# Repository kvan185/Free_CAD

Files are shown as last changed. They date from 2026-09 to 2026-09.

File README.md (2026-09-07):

# HỆ THỐNG TRỐNG RANG: CÁNH ĐẢO LA SẮT CHẠM CÂY TRỤ ĐỂ HÀN VÀO & 10 CÂY CHỐNG XEN KẼ (FREECAD 3D)

---

## 1. Thông Số Kỹ Thuật: Cánh Đảo Trong Chạm Trực Tiếp Cây Trụ Để Hàn Vào

### A. 5 CÁNH ĐẢO TRONG (BẢN RỘNG 10CM, DÀY 0.8CM, DÀI 65CM, KÉO DÀI RA PHÍA SAU)
- **Vật liệu**: Thanh la sắt bản rộng **$10\text{ cm}$ ($100\text{ mm}$)**, dày **$0.8\text{ cm}$ ($8\text{ mm}$)**.
- **Vị trí theo bán kính (Nằm ngay giữa thân 5 cây chống)**:
  - Cây chống dài từ cây láp ($R = 32.5\text{ mm}$) đến thành trống ($R = 392\text{ mm}$), có điểm chính giữa ở $R = 212.25\text{ mm}$.
  - Cánh đảo trong bản $10\text{ cm}$ được đặt đối xứng ngay điểm giữa: **$R_{\text{in}} = 162\text{ mm} \rightarrow R_{\text{out}} = 262\text{ mm}$** (tâm cánh $R = 212\text{ mm}$).
  - **Khoảng cách đến cây láp**: Cách mặt cây láp **$129.5\text{ mm}$ ($\approx 13\text{ cm}$)** $\rightarrow$ **Tuyệt đối KHÔNG áp sát vào cây láp, tạo khoảng trống thông thoáng cực lớn quanh trục.**
  - **Khoảng cách đến vỏ trống**: $130\text{ mm}$ ($13\text{ cm}$) đối xứng hoàn hảo.
  - **Khoảng cách đến cánh ngoài**: Cách mép trong cánh ngoài $60\text{ mm}$ ($6\text{ cm}$).
- **Vị trí dọc trục & Chiều dài (Kéo dài ra phía sau)**:
  - Chiều dài: **$65\text{ cm}$ ($650\text{ mm}$)**.
  - Trải từ tầng 5 cây chống gần đầu ($Y = -400\text{ mm}$), đi xuyên qua và gối hàn lên tầng 5 cây chống giữa ($Y = +100\text{ mm}$), rồi **kéo dài tiếp thêm $15\text{ cm}$ về phía sau** đến $Y = +250\text{ mm}$.
  - Cách miệng sau của trống $25\text{ cm}$ để luồng gió hút khói và cửa cấp hạt thông thoáng hoàn hảo.
- **Bước xoắn & Góc xoắn**: Bước xoắn $P = 1083.3\text{ mm}$, `lefthand = True` $\rightarrow$ Xoắn ngược đúng **$6/10$ vòng ($216^\circ$)**.
- **Tác dụng**: Đón dòng hạt rơi từ đỉnh xuống vùng giữa và hắt ngược lại theo chiều $Y-$, tạo luồng đối lưu tuần hoàn liên tục.
- **Phân bố**: 5 cánh ở các góc **$36^\circ, 108^\circ, 180^\circ, 252^\circ, 324^\circ$**.
- **Màu hiển thị 3D**: Xanh ngọc lục bảo tươi sáng.

---

### B. 5 CÁNH ĐẢO NGOÀI (CHẠM 5 CÂY CHỐNG ĐỂ HÀN & BÁM THÀNH TRỐNG)
- **Vật liệu**: Thanh la sắt bản rộng **$7\text{ cm}$ ($70\text{ mm}$)**, dày **$0.5\text{ cm}$ ($5\text{ mm}$)**.
- **Bán kính làm việc**: Cạnh ngoài bám sát thành trong trống $R = 392\text{ mm}$, cạnh trong $R = 322\text{ mm}$ (cao đứng đúng $7\text{ cm}$).
- **Chiều dài trục**: $H = 960\text{ mm}$ (từ $Y = -480\text{ mm}$ đến $+480\text{ mm}$).
- **Bước xoắn & Độ xoắn**: $P = 1600.0\text{ mm}$ $\rightarrow$ **Giữ nguyên chuẩn xác độ xoắn $6/10$ vòng ($216.0^\circ$)**.
- **Căn chỉnh pha tiếp xúc hàn**:
  - Tại vị trí tầng 5 cây chống bên 1 ($Y = -400\text{ mm}$), quãng đường xoắn từ gốc $Y = -480\text{ mm}$ là $\Delta Y = 80\text{ mm}$.
  - Góc xoắn tích lũy tại $Y = -400\text{ mm}$ là: $\frac{80}{1600} \times 360^\circ = +18.0^\circ$.
  - Bù góc lệch pha ban đầu: **`offset_goc = -18.0°`**.
  - **Kết quả**: Tại $Y = -400\text{ mm}$, cả 5 cánh đảo ngoài đi qua chính xác các góc $0^\circ, 72^\circ, 144^\circ, 216^\circ, 288^\circ$, **chạm khít 100% không còn khe hở vào 5 cây chống để thợ hàn đính/hàn ngấu liên kết chắc chắn!**
- **Tác dụng**: Cào sát thành trống, cuốn và xúc hạt cuộn tịnh tiến xuôi liên tục theo chiều $Y+$.
- **Màu hiển thị 3D**: Đỏ cam nổi bật.

---

### C. HỆ THỐNG 10 CÂY CHỐNG BỐ TRÍ XEN KẼ NHAU (VỪA CHẠM CẢ 2 TẦNG ĐỂ HÀN)
- **Vật liệu**: **Ống sắt tròn $\varnothing 20\text{ mm}$, rỗng ruột, dày $2\text{ mm}$** (ĐK trong $\varnothing 16\text{ mm}$).
- **Bên 1 - 5 cây gần đầu** (Cách miệng trống $10\text{ cm}$ $\rightarrow$ $Y = -400\text{ mm}$):
  - Góc ban đầu: Bù góc pha **$-4.5^\circ$** $\rightarrow$ Các góc: **$-4.5^\circ, 67.5^\circ, 139.5^\circ, 211.5^\circ, 283.5^\circ$**.
  - **Tiếp xúc**: Vừa chạm sát sườn mặt bên của 5 cánh ngoài la sắt (khoảng cách $0.687\text{ mm}$), **hoàn toàn giống như 5 cây ở giữa**, không bị cắt xẻ vào lòng ống, tạo góc tiếp xúc lý tưởng để thợ hàn đường hàn ngấu.
- **Bên 2 - 5 cây ở giữa** (Cách miệng lỗ đầu kia $40\text{ cm}$ $\rightarrow$ $Y = +100\text{ mm}$):
  - Góc ban đầu: **$+36.0^\circ$** $\rightarrow$ Các góc: **$36^\circ, 108^\circ, 180^\circ, 252^\circ, 324^\circ$**.
  - **Tiếp xúc**: Vừa chạm sát sườn mặt bên của 5 cánh ngoài (khoảng cách $0.687\text{ mm}$).
- **Tổng kết**: Cả 10 cây chống đều tiếp xúc tiếp tuyến êm ái ("vừa chạm") với 5 cánh ngoài để hàn.

---

### D. HỆ THỐNG TRỐNG RANG 2 LỚP CÁCH KHÍ & CÂY LÁP
- **Vỏ trống trong**: Dài $1\text{ m}$ ($1000\text{ mm}$), đường kính ngoài $80\text{ cm}$ ($800\text{ mm}$), thành dày $0.8\text{ cm}$ ($8\text{ mm}$, $R_{\text{in}} = 392\text{ mm} \rightarrow R_{\text{out}} = 400\text{ mm}$).
- **Lớp áo ngoài cách khí**:
  - Hở **$1\text{ cm}$ ($10\text{ mm}$)** đệm không khí so với vỏ trong ($R_{\text{ao\_in}} = 410\text{ mm}$).
  - Độ dày vỏ ngoài: **$0.5\text{ cm}$ ($5\text{ mm}$)** ($R_{\text{ao\_out}} = 415\text{ mm} \rightarrow \varnothing 830\text{ mm} = 83\text{ cm}$).
  - Chiều dài: $1\text{ m}$ ($1000\text{ mm}$).
  - **Tác dụng**: Tạo lớp đệm khí cách nhiệt chống táp lửa trực tiếp, tránh cháy xém hạt và giữ nhiệt đối lưu hoàn hảo.
- **Cây láp (cây trụ chính)**: Dài tổng $1\text{ m}2$ ($1200\text{ mm}$), thân giữa $\varnothing 65\text{ mm} \times 1000\text{ mm}$ ($R = 32.5\text{ mm}$), 2 đầu tiện bậc $\varnothing 60\text{ mm} \times 10\text{ cm}$ ($100\text{ mm}$).

### E. HỆ THỐNG 2 MẶT MÁY GÁ TRỐNG (TRƯỚC & SAU): SẮT TẤM DÀY 1.8CM, VÒNG TRÒN PHI 96CM, HÌNH THANG CHÂN 1.1M
- **Vật liệu & Độ dày**: Sắt tấm kết cấu chịu lực dày **$1.8\text{ cm}$ ($18\text{ mm}$ / 18 ly)** nguyên khối.
- **Bố trí 2 đầu máy đối xứng gá trống**:
  - **Mặt máy trước**: Tọa độ $Y = -518.0\text{ mm} \rightarrow -500.0\text{ mm}$ (ngay miệng trước của trống).
  - **Mặt máy sau**: Tọa độ $Y = +500.0\text{ mm} \rightarrow +518.0\text{ mm}$ (ngay miệng sau của trống).
  - Khoảng cách lọt lòng giữa 2 mặt máy: Đúng **$1000\text{ mm} = 1.0\text{ m}$**, ôm trọn chiều dài thân trống rang.
- **Phía trên hình tròn lớn hơn 10cm cong thắt eo vào 1 tí**:
  - Cung tròn bán kính $R = 480\text{ mm}$ (**$\varnothing 960\text{ mm} = 96\text{ cm}$**, lớn hơn $10\text{ cm}$ so với $\varnothing 86\text{ cm}$ trước đó), bao phủ rộng rãi lớp vỏ áo ngoài ($R_{\text{ao}} = 415\text{ mm}$) với vành gờ che bảo vệ an toàn $65\text{ mm}$ ($6.5\text{ cm}$) mỗi bên.
  - Cung tròn uốn cong qua đường xích đạo ($Z = 0$), tiếp tục thắt cong vào trong 1 tí đến góc $-40^\circ$ ($X = \pm 367.7\text{ mm}, Z = -308.5\text{ mm}$) ôm sát theo sườn dưới của trống.
- **Phía dưới kết hợp liền khối thành hình thang cân (bên dưới dài hơn bên trên)**:
  - **Đáy trên của hình thang**: Chính là eo thắt cong vào của cung tròn, bề rộng $W_{\text{top}} = 735.4\text{ mm} \approx 735\text{ mm}$ tại $Z = -308.5\text{ mm}$.
  - **Đáy dưới của hình thang**: Nằm phẳng trên sàn xưởng tại $Z = -850.0\text{ mm}$, bề rộng **$W_{\text{bottom}} = 1100\text{ mm} = 1.1\text{ m}$** ($X = -550\text{ mm} \rightarrow +550\text{ mm}$).
  - Đúng chuẩn hình thang cân với **đáy dưới ($1100\text{ mm}$) dài hơn đáy trên ($735\text{ mm}$)**.
  - Hai cạnh sườn xiên choãi xuống mặt đất với góc nghiêng $\approx 71.4^\circ$.
  - Tổng chiều cao mặt máy từ đỉnh vòng tròn đến đáy phẳng là **$1330\text{ mm}$ ($1.33\text{ m}$)** (từ $Z = -850\text{ mm}$ đến $Z = +480\text{ mm}$).
  - **Tác dụng**: Cặp chân đế phẳng siêu rộng $1.1\text{ m}$ ở hai đầu tiếp xúc vững chắc trên mặt sàn hoặc dễ dàng bắt bu-lông vào dầm thép bệ máy, chống rung lắc, chống lật tuyệt đối khi trống quay đảo hàng tạ nông sản.
- **Lỗ lọt đầu cốt ở cả 2 mặt máy**: Mỗi mặt có 1 lỗ tròn đường kính **$\varnothing 65\text{ mm}$** ($R = 32.5\text{ mm}$) tại tâm $(0, 0)$, lọt đầu cốt láp $\varnothing 60\text{ mm}$ với khe hở an toàn $2.5\text{ mm}$ đều quanh cốt. Mỗi đầu cốt láp nhô ra ngoài mặt bích đúng **$82\text{ mm}$** để gá lắp gối bi đỡ trục (UCP/UCFL) và puly/nhông xích truyền động.
- **Tính năng cơ học**: Cả 2 mặt máy là chi tiết **tĩnh (cố định vào khung bệ máy)**, đứng yên làm bệ đỡ vững chắc cho toàn bộ trống quay.

---

### G. MIỆNG RA HÀNG TẠI MẶT TRƯỚC: DÀI 50CM, 2 BÊN THÀNH CAO ĐÚNG 10CM (TỪ MÉP DƯỚI LÊN), ĐÁY CONG THEO TRỐNG R392MM
- **Vị trí gia công**: Cắt xuyên thủng qua tấm thép dày **$1.8\text{ cm}$ ($18\text{ mm}$)** của Mặt máy trước (`obj_mat_truoc`, $Y = -518\text{ mm} \rightarrow -500\text{ mm}$). Mặt máy sau giữ liền khối kín 100% để chống lọt khí.
- **Biên dạng hình học chuẩn xác**:
  - **2 bên thành đứng**: Cao đúng **$10\text{ cm} = 100\text{ mm}$** tính từ mép dưới của cung tròn lòng trống ($Z = -301.9\text{ mm}$) thẳng đứng lên ($Z = -201.9\text{ mm}$) tại hai bên biên $X = -250.0\text{ mm}$ và $X = +250.0\text{ mm}$.
  - **Cạnh trên (Đường thẳng)**: Đường thẳng nằm ngang dài đúng **$50\text{ cm} = 500\text{ mm}$** (từ $X = -250\text{ mm}$ đến $X = +250\text{ mm}$) tại cao độ $Z = -201.9\text{ mm}$.
  - **Cạnh dưới (Đường cong theo trống)**: Cung tròn uốn cong ôm sát thành trong của trống rang với bán kính **$R = 392\text{ mm}$** (từ $X = -250\text{ mm}, Z = -301.9\text{ mm}$ qua đáy thấp nhất $X = 0, Z = -392.0\text{ mm}$ đến $X = +250\text{ mm}, Z = -301.9\text{ mm}$).
  - **Chiều cao lớn nhất tại tâm (từ đáy lên đỉnh)**: Đạt **$190\text{ mm} = 19.0\text{ cm}$** (từ $Z = -392.0\text{ mm}$ lên $Z = -201.9\text{ mm}$), mở rộng khẩu độ đón luồng hạt trút ra cực kỳ thông thoáng.
- **Ưu điểm cơ khí & Công năng vận hành**:
  - **Xả sạch 100% không đọng hạt**: Đáy miệng xả trùng khớp hoàn hảo với thành trong lòng trống ($R = 392\text{ mm}$), không có bất kỳ gờ hay bậc cản nào $\rightarrow$ Nông sản/cà phê sau khi rang chín được các cánh đảo ngoài xúc trút trơn tru ra ngoài không hề bị sót hay vướng cháy khét.
  - **Đảm bảo độ cứng vững kết cấu**: Khoảng "thịt" thép nguyên khối chịu lực giữa cạnh trên miệng xả ($Z = -201.9\text{ mm}$) và mép dưới lỗ cốt trục $\varnothing 65\text{ mm}$ ($Z = -32.5\text{ mm}$) còn tới **$169.4\text{ mm} \approx 17\text{ cm}$**. Tấm thép 18 ly siêu dày giữ vững độ cứng chịu tải rung động mà không hề bị võng hay biến dạng.
  - **Khoảng sáng xả liệu thoáng rộng**: Từ đáy miệng xả ($Z = -392\text{ mm}$) xuống mặt tấm chân đế ($Z = -850\text{ mm}$) có khoảng cách tĩnh lên đến **$458\text{ mm} \approx 46\text{ cm}$**, cực kỳ thuận tiện để bố trí máng hứng, phễu rót và đưa bàn làm nguội/thau hứng cà phê vào bên dưới.

---

### H. LỖ THĂM HÀNG PHI 30MM & CÂY THĂM HÀNG NẰM NGANG CÂY LÁP (KHÔNG CẤN CÁNH ĐẢO)
- **Vị trí gia công trên Mặt máy trước**:
  - Tọa độ tâm lỗ: **Nằm ngang cây láp ($Z = 0.0\text{ mm}$)**, bố trí phía bên trái tại **$X = -200.0\text{ mm}, Z = 0.0\text{ mm}$** (vị trí góc 9 giờ đón trọn dòng hạt cuộn trút xuống).
  - Đường kính lỗ: **$\varnothing 30\text{ mm}$ ($R = 15\text{ mm}$)**, khoan xát xiên qua tấm sắt dày $1.8\text{ cm}$ ($18\text{ mm}$) của mặt máy trước.
- **Cấu tạo Cây thăm hàng (Trier / Sampler spoon)**:
  - **Thân ống & Máng xúc mẫu (Inox)**: Ống inox $\varnothing 24\text{ mm}$, có bích chặn $\varnothing 38\text{ mm}$ tì lên mặt ngoài. Chiều sâu đút vào trống $7.2\text{ cm}$ (đầu tip tại $Y = -427.6\text{ mm}$), phay rãnh lòng máng ngửa lên trên ($+Z$) hứng trọn hạt rơi.
  - **Tay cầm cách nhiệt**: Gỗ tiện công thái học $\varnothing 32\text{ mm}$, dài $11\text{ cm}$, nhô ngang sang bên trái phía trước mặt máy tại cao độ $Z = 0$, chống nóng an toàn tuyệt đối khi rút/xoay lấy mẫu thử.
- **Tư thế lắp đặt: ĐỂ XÉO TRONG MẶT PHẲNG NẰM NGANG ($Z = 0$)**:
  - Góc xiên vào tâm: $\approx 16.7^\circ$ trong mặt phẳng nằm ngang ($Z = 0.0\text{ mm}$, vector $\vec{V} = (30, 100, 0)$) hướng chếch vào lòng trống.
  - Hướng miệng xúc mẫu: Ngửa thẳng lên trên ($+Z$) để dòng nông sản/hạt cà phê đảo cuộn từ đỉnh trống rơi tự nhiên lọt đầy máng.
- **Tính toán cơ khí: TUYỆT ĐỐI KHÔNG CẤN CÁNH ĐẢO**:
  - **Với 5 Cánh đảo ngoài ($R = 322 - 392\text{ mm}$)**: Cây thăm nằm ở bán kính $R = 175.6\text{ mm}$, cách xa mép trong cánh ngoài tới **$146.4\text{ mm} \approx 14.6\text{ cm}$** $\rightarrow$ Tuyệt đối an toàn.
  - **Với 10 Cây chống tròn ($\varnothing 20\text{ mm}$ tại $Y = -400\text{ mm}$)**: Đầu tip cây thăm dừng tại $Y = -427.6\text{ mm}$, cách mép cây chống tới **$17.6\text{ mm}$** khoảng hở an toàn.
  - **Với 5 Cánh đảo trong (bắt đầu tại $Y = -400\text{ mm}$)**: Cây thăm cách đầu cánh trong tới **$27.6\text{ mm}$**.
  - **Với Cốt trục chính / Cây láp ($\varnothing 65\text{ mm}$, $R = 32.5\text{ mm}$)**: Cách mặt trục láp tới **$143.1\text{ mm} \approx 14.3\text{ cm}$**.
  - **Kết luận**: Cây thăm hàng nằm ngang trục láp đạt độ tiện dụng tối ưu, đứng yên hoặc xoay rút lấy mẫu trơn tru khi máy đang vận hành mà không hề va quẹt vào bất kỳ chi tiết quay nào!

---

### I. CỬA BUỒNG ĐỐT MẶT SAU: LỖ 50x30CM, TẬN DỤNG TẤM SẮT ĐÃ CẮT LÀM CỬA, KHE CẮT 1MM, 2 BẢN LỀ MỞ VỀ BÊN TRÁI
- **Vị trí gia công**: Cắt bằng máy CNC xuyên thủng qua tấm thép dày **$1.8\text{ cm}$ ($18\text{ mm}$)** của Mặt máy sau (`obj_mat_sau`, $Y = +500.0\text{ mm} \rightarrow +518.0\text{ mm}$).
- **Kích thước lỗ khoét khung**:
  - **Chiều dài (bề rộng theo phương ngang)**: **$50\text{ cm} = 500\text{ mm}$**, cân đối chính giữa từ $X = -250.0\text{ mm}$ đến $X = +250.0\text{ mm}$.
  - **Chiều cao (theo phương đứng)**: Giảm còn đúng **$30\text{ cm} = 300\text{ mm}$** (từ $Z = -800.0\text{ mm}$ lên $Z = -500.0\text{ mm}$).
  - **Khoảng cách tới chân máy**: Đáy mép dưới đặt tại **$Z = -800.0\text{ mm}$**, cách chân đế máy ($Z = -850.0\text{ mm}$) đúng **$5\text{ cm} = 50\text{ mm}$**.
- **Cấu tạo cánh cửa tận dụng phôi sắt đã cắt (Kerf cắt 1mm)**:
  - **Dùng lại tấm sắt 18mm đã cắt**: Tiết kiệm vật tư tối đa, vừa khít hoàn hảo vào khung cửa.
  - **Đường cắt (kerf) chuẩn CNC**: Chừa khe hở đều **$1.0\text{ mm}$** cả 4 cạnh xung quanh:
    - Kích thước cánh cửa: Rộng **$49.8\text{ cm} = 498\text{ mm}$** x Cao **$29.8\text{ cm} = 298\text{ mm}$** x Dày **$1.8\text{ cm} = 18\text{ mm}$**.
- **Hệ thống 2 bản lề cối & Khóa cửa (Mở về bên trái)**:
  - **2 Bản lề cối hàn bên trái**: Hàn dọc mép bên trái ($X = +249.5\text{ mm}$, $Y = 518\text{ mm}$ khi đứng nhìn từ phía sau), bố trí tại cao độ $Z = -560\text{ mm}$ và $Z = -740\text{ mm}$. Cối đường kính $\varnothing 20\text{ mm}$ chịu lực siêu bền, cho phép **cánh cửa mở xoay mượt mà về bên trái** góc từ $0^\circ$ đến $120^\circ$.
  - **Tay khóa then gài L-handle bên phải**: Bố trí tại $X = -210\text{ mm}, Z = -650\text{ mm}$, có lưỡi gài giữ chặt cánh cửa khi đóng kín buồng đốt.
- **Tính toán cơ khí & Khoảng cách an toàn**:
  - **Khoảng thịt thép lên cốt trục láp**: Từ đỉnh lỗ ($Z = -500.0\text{ mm}$) lên tới lỗ cốt láp $\varnothing 65\text{ mm}$ ($Z = -32.5\text{ mm}$) tăng lên tới **$467.5\text{ mm} \approx 47\text{ cm}$** thép tấm 18 ly nguyên khối $\rightarrow$ Cực kỳ cứng vững, chống rung lắc hoàn toàn.
  - **Khoảng cách tới gầm trống rang**: Cách đáy vỏ ngoài trống ($Z = -415\text{ mm}$) tới **$85\text{ mm} = 8.5\text{ cm}$** dải thép liền khối bảo vệ.
- **Công năng vận hành thực tế**:
  - Đóng vai trò là **Cửa buồng đốt củi / nạp nhiệt / thông gió**: Dễ dàng mở cửa về bên trái để đưa củi lửa hoặc đầu đốt gas vào, đóng kín cửa khi rang để giữ nhiệt, và mở ra vệ sinh cào tro xỉ định kỳ cực kỳ tiện lợi.

---

### J. BUỒNG ĐỐT CỦI & LÒNG MÁNG GẠCH SA MỐT CAO 50CM ÔM TRỐNG CÁCH 1CM GIỮ NHIỆT TUYỆT ĐỐI (KT 30x5x10CM)
- **Yêu cầu thiết kế**: "tôi chỉ cần gạch cao lên 50cm thôi".
- **Kích thước từng viên gạch sa mốt tiêu chuẩn**:
  - Chiều dài: **$30\text{ cm} = 300.0\text{ mm}$**
  - Chiều rộng: **$10\text{ cm} = 100.0\text{ mm}$**
  - Chiều dày: **$5\text{ cm} = 50.0\text{ mm}$**
  - Mạch vữa xây chịu nhiệt: $1.5\text{ mm}$ sắc nét mô phỏng chân thực kết cấu xây lò.
- **Cấu tạo không gian 3 thành phần & Kỹ thuật cưa gọt gạch ôm sát trống (Nằm gọn dưới trống)**:
  1. **Sàn đáy buồng đốt (Hearth Floor)**:
     - Lát kín trực tiếp trên mặt tấm sắt chân máy từ $Z = -850.0\text{ mm}$ đến $Z = -800.0\text{ mm}$ (dày đúng $5\text{ cm} = 50\text{ mm}$, 1 viên gạch nằm).
     - **Bảo vệ cách nhiệt $100\%$**: Ngăn chặn hoàn toàn nhiệt độ cực cao của than hồng ($800 - 1000^\circ\text{C}$) truyền xuống tấm sắt chân máy $5\text{ mm}$ và sàn xưởng, chống cong vênh bệ máy.
     - **Bằng phẳng khít mép dưới cửa sau**: Mặt sàn gạch ở cao độ $Z = -800.0\text{ mm}$, trùng khớp $100\%$ với ngưỡng dưới của cửa sau ($Z = -800.0\text{ mm}$), giúp thao tác đưa củi vào và cào tro xỉ ra trơn tru tuyệt đối, không có gờ cản trở.
     - Kích thước sàn: Rộng **$700\text{ mm} = 70\text{ cm}$** ($7$ hàng gạch $\times 100\text{ mm}$, $X \in [-350, +350\text{ mm}]$), Dài **$1000\text{ mm} = 1\text{ m}$** ($Y \in [-500, +500\text{ mm}]$) xây so le các hàng.
  2. **Hai vách hông bao đúng 1 lớp gạch dày $10\text{ cm}$, chừa lòng ngang $50\text{ cm}$, cao 9 hàng đến đáy trống**:
     - **Lòng trong chừa đúng ngang $50\text{ cm} = 500\text{ mm}$**: $X \in [-250, +250\text{ mm}]$, khớp hoàn hảo $100\%$ với chiều rộng cửa sau $50\text{ cm}$.
     - **Bao quanh đúng 1 lớp gạch (dày $10\text{ cm} = 100\text{ mm}$)**: Vách trái từ $X \in [-350, -250\text{ mm}]$, vách phải từ $X \in [+250, +350\text{ mm}]$.
     - **Tổng bề rộng phủ bì chỉ $70\text{ cm} = 700\text{ mm}$**: Nhỏ hơn bề rộng eo thắt hẹp nhất của mặt máy ($73.5\text{ cm}$, $X = \pm 367.7\text{ mm}$) $\rightarrow$ Dư an toàn ít nhất $1.8\text{ cm}$ mỗi bên, **lọt thỏm hoàn toàn dưới gầm trống và bên trong mặt máy, tuyệt đối không bị lòi ra ngoài!**
     - **Chiều cao xây đến đáy trống**: Xây **9 hàng gạch** ($45\text{ cm}$ từ sàn gạch, $50\text{ cm}$ từ chân máy) lên tới $Z = -350.0\text{ mm}$.
     - **Kỹ thuật cưa gọt gạch tạo hình ($R_{\text{cắt}} = 425.0\text{ mm}$)**: Cắt vát vòm cong trụ tròn bán kính **$R_{\text{cut}} = 425.0\text{ mm}$** dọc theo trục $Y$.
     - **Khe hở giữ nhiệt tuyệt đối $1\text{ cm} = 10\text{ mm}$**: So với bán kính vỏ áo ngoài $R_{\text{ao}} = 415.0\text{ mm}$, khoảng hở tròn đều là **$425 - 415 = 10.0\text{ mm} = 1\text{ cm}$** ôm sát quanh đáy trống.
     - **Hiệu quả nhiệt động học**: Khí nóng và bức xạ từ than củi bị bẫy kín trong khe hở $1\text{ cm}$ ôm quanh thân trống, không cho nhiệt lượng thoát sang hai bên hông máy, giúp tiết kiệm củi tối đa và tăng tốc độ gia nhiệt trống rang.
  3. **Vách chắn nhiệt phía trước (Front Wall)**:
     - Xây chắn ở đầu trước: $Y \in [-500, -400\text{ mm}]$ (dày $10\text{ cm}$), $X \in [-250, +250\text{ mm}]$ (rộng $50\text{ cm}$).
     - Đỉnh vách được gọt vòm cong $R_{\text{cut}} = 425\text{ mm}$ ôm cách đáy trống ngoài $1\text{ cm}$ (đỉnh tại $X=0$ đạt $Z = -425\text{ mm}$).
     - **Hoàn toàn không cấn miệng ra hàng**: Miệng ra hàng mặt trước nằm từ $Z = -302\text{ mm}$ lên $Z = -202\text{ mm}$, cao hơn đỉnh vách trước tới $123\text{ mm} \approx 12.3\text{ cm}$ $\rightarrow$ Hạt xả trút $100\%$ không bị vướng.
- **Kích thước lòng buồng đốt**: Rộng **$50\text{ cm}$** $\times$ Chiều dài buồng đốt **$90\text{ cm}$** ($Y \in [-400, +500\text{ mm}]$), chứa thoải mái củi dài $60 - 80\text{ cm}$.
- **Cào tro và nạp củi thuận tiện qua cửa sau 50x30cm**: Đáy cửa sau phẳng lì tiếp nối mặt sàn gạch sa mốt, cào tro xỉ ra ngoài dễ dàng trong 1 nốt nhạc.

---

### F. HỆ THỐNG CHÂN ĐẾ MÁY HÌNH CHỮ NHẬT: SẮT TẤM DÀY 0.5CM (5MM), DƯ MỖI BÊN 0.5CM (5MM)
- **Vật liệu & Độ dày**: Thép tấm kết cấu dày chuẩn **$0.5\text{ cm} = 5.0\text{ mm}$ (5 ly)** nguyên tấm.
- **Kích thước bao chuẩn xác tuyệt đối**:
  - **Bề ngang máy (Trục $X$ - Trái & Phải)**:
    - Đáy chân 2 mặt máy có bề rộng $1100.0\text{ mm} = 1.1\text{ m}$ ($X = -550.0\text{ mm} \rightarrow +550.0\text{ mm}$).
    - Dư ra mỗi bên trái và phải đúng **$0.5\text{ cm} = 5.0\text{ mm}$** $\rightarrow$ Biên $X = -555.0\text{ mm} \rightarrow +555.0\text{ mm}$.
    - **Tổng chiều rộng chân đế**: **$W = 1110.0\text{ mm} = 111.0\text{ cm} = 1.11\text{ m}$**.
  - **Chiều dọc máy (Trục $Y$ - Trước & Sau)**:
    - Mặt ngoài mặt máy trước tại $Y = -518.0\text{ mm}$, mặt ngoài mặt máy sau tại $Y = +518.0\text{ mm}$ (khoảng bao phủ $1036.0\text{ mm}$).
    - Dư ra mỗi bên trước và sau đúng **$0.5\text{ cm} = 5.0\text{ mm}$** $\rightarrow$ Biên $Y = -523.0\text{ mm} \rightarrow +523.0\text{ mm}$.
    - **Tổng chiều dài chân đế**: **$L = 1046.0\text{ mm} = 104.6\text{ cm} = 1.046\text{ m}$**.
  - **Chiều cao & Cao độ lắp đặt (Trục $Z$)**:
    - Độ dày tấm: $H = 5.0\text{ mm}$.
    - Đáy 2 mặt máy tựa khít lên mặt trên của chân đế tại $Z = -850.0\text{ mm}$.
    - Mặt dưới chân đế tiếp xúc mặt sàn tại $Z = -855.0\text{ mm}$ (Điểm gốc: $X = -555.0, Y = -523.0, Z = -855.0\text{ mm}$).
- **Tác dụng cơ khí**:
  - Khóa cứng và liên kết 2 mặt máy trước - sau thành một khối khung giằng chassi hoàn chỉnh.
  - Phân bổ đều trọng lượng máy (hàng trăm kg) xuống mặt nền xưởng, triệt tiêu hoàn toàn ứng suất rung lắc khi trống quay đảo nông sản tải nặng.
  - Vành gờ dư $5\text{ mm}$ đều 4 phía tạo đường rãnh chuẩn cho thợ cơ khí chạy đường hàn góc liên kết bệ máy hoặc khoan lỗ bắt bu-lông neo chân đế (anchor bolts).

---

## 2. Bảng Điều Khiển Thông Minh (Smart Control Dashboard)
- **Auto-Clean**: Tự động đóng tất cả tab cũ trong FreeCAD trước khi mở mới.
- **Giao diện tinh gọn, thông minh**: Xóa bỏ toàn bộ khối văn bản thừa rườm rà trên hộp thoại, chuyển toàn bộ thông số kỹ thuật chi tiết vào tài liệu markdown [`THONG_SO_KY_THUAT.md`](file:///c:/VAN/CAD/THONG_SO_KY_THUAT.md).
- **Nút "📖 Thông Số (MD)"**: Đặt ngay thanh tiêu đề, 1-click mở ngay tài liệu kỹ thuật đầy đủ.
- **Thanh trạng thái sống (Live Status)**: Hiển thị thời gian thực trạng thái quay động cơ (`🟢 Đang quay` / `🔴 Đã tạm dừng`), góc xoay độ, chiều quay (Thuận / Nghịch) và trạng thái cửa sau (Đóng / Mở 120°).
- **Preset tốc độ thông minh (1-Click Speed)**: Thanh trượt 5 - 120 RPM kèm các nút chọn nhanh `20 RPM (Chậm)`, `40 RPM (Chuẩn)`, `60 RPM (Nhanh)`.
- **Nút "🚪 Mở Cửa Sau (120°)"**: Cơ cấu cửa xoay mở rộng **$120^\circ$** về bên trái, áp sát sườn máy, giải phóng $100\%$ miệng cửa để nạp củi và cào tro phẳng đáy sàn gạch.
- **Nhóm Quan sát**: `👁 Xuyên Thấu Vỏ Trống` (transparency 50%), `📦 Ẩn/Hiện Vỏ Trống`, `🛡 Ẩn/Hiện Khung Bệ Máy`, `🧱 Ẩn/Hiện Lò Gạch Sa Mốt`.
- **Góc nhìn camera thông minh 1-Click**:
  - `📐 Isometric`: Căn góc nhìn phối cảnh 3D tiêu chuẩn.
  - `🔙 Mặt Sau (Lò Gạch)`: Tự động căn góc nhìn thẳng vào cửa sau và lòng buồng đốt.
  - `🔜 Mặt Trước (Miệng Xả)`: Tự động căn góc nhìn thẳng vào miệng xả hàng và cây thăm inox.
  - `🔄 Đổi Tư Thế Đứng / Ngang`.

---

## 3. Cách Khởi Chạy Ngay Trong FreeCAD
1. Mở phần mềm **FreeCAD**.
2. Trên thanh menu, vào **Macro** $\rightarrow$ **Macros...**
3. Chọn file **`trong_hinh_tru.FCMacro`** $\rightarrow$ Bấm **Execute**.
4. Toàn bộ mô hình máy rang với **buồng đốt củi lót gạch chịu lửa 30x5x10cm nằm gọn dưới gầm trống, cửa buồng đốt mở rộng 120 độ, miệng xả 50x10cm đáy cong, cây thăm hàng inox ngang cốt láp, 2 mặt máy trước sau 1.8cm, trống 2 lớp cách khí 1cm và hệ thống 10 cánh đảo** sẽ xuất hiện cùng **bảng điều khiển thông minh mới** sẵn sàng vận hành!

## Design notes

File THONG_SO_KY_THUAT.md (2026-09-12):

# BẢNG THÔNG SỐ KỸ THUẬT CHI TIẾT: MÁY RANG CỦI 2 LỚP CÁCH KHÍ & KHUNG BỆ ĐẾ

> **Tài liệu kỹ thuật chính thức**  
> *Được trích xuất và tổng hợp toàn bộ từ hệ thống điều khiển mô phỏng FreeCAD 3D.*

---

## 1. Vỏ Trống Rang 2 Lớp (Đệm Khí Cách Nhiệt 1cm & Khe Hở Vận Hành Chuẩn Xác)
* **Vỏ trong**:
  * Chiều dài: Giữ nguyên vẹn **$1000\text{ mm} = 100\text{ cm} = 1\text{ m}$**.
  * Tọa độ trục $Y$: $Y \in [-499.5\text{ mm}, +500.5\text{ mm}]$.
  * **Khe hở đầu trước áp sát mặt máy**: Đúng **$0.5\text{ mm}$** so với mặt trong của Mặt Máy Trước ($Y = -500.0\text{ mm}$), chống cạ quẹt khi trống quay, tuyệt đối không lọt hạt.
  * **Khe hở đầu sau buồng thoát nhiệt**: Đúng **$99.5\text{ mm} = 9.95\text{ cm}$** so với mặt trong của Mặt Máy Sau ($Y = +600.0\text{ mm}$), tạo khoảng không thông thoáng lý tưởng cho luồng khí nóng đối lưu và khói thoát lên ống thu khói.
  * Đường kính ngoài: $\varnothing 800\text{ mm} = 80\text{ cm}$ (Bán kính ngoài $R_{\text{out}} = 400\text{ mm}$).
  * Độ dày thành sắt: $8\text{ mm} = 0.8\text{ cm}$ (Bán kính trong $R_{\text{in}} = 392\text{ mm}$).
* **Vỏ áo ngoài (Áo giữ nhiệt)**:
  * Chiều dài: $1000\text{ mm} = 1\text{ m}$ ($Y \in [-499.5\text{ mm}, +500.5\text{ mm}]$).
  * Bán kính trong: $R_{\text{ao\_in}} = 410\text{ mm}$ (Tạo đệm không khí $10\text{ mm} = 1\text{ cm}$ so với vỏ trong).
  * Độ dày vỏ ngoài: $5\text{ mm} = 0.5\text{ cm}$ (Bán kính ngoài $R_{\text{ao\_out}} = 415\text{ mm} \rightarrow \varnothing 830\text{ mm} = 83\text{ cm}$).
* **Tác dụng nhiệt động**: Lớp không khí tĩnh $1\text{ cm}$ giữa 2 vỏ hoạt động như một lớp đệm nhiệt, ngăn chặn táp lửa trực tiếp từ ngọn lửa củi, chống cháy xém hạt nông sản và giữ nhiệt đối lưu cực tốt.

---

## 1b. Tấm Sắt Tròn Đáy Sau Trống Rang (Hàn Âm Lọt Lòng Vòng Tròn Nhỏ Phi 78.4cm)
* **Ý tưởng thiết kế (Trường hợp 2 được chọn)**: Bịt kín hoàn toàn đuôi sau của **Vòng tròn nhỏ bên trong** (`Trong_Hinh_Tru_Sat`) để hạt cà phê không bị rơi ra ngoài buồng đốt trong quá trình rang, đồng thời giữ nguyên vẹn luồng đệm khí cách nhiệt $1\text{ cm}$ và khoảng hở sau $9.95\text{ cm}$.
* **Quy cách hình học**:
  * **Đường kính ngoài đĩa**: $\varnothing 784.0\text{ mm} = 78.4\text{ cm}$ ($R = 392.0\text{ mm}$), khớp chính xác với đường kính lọt lòng của vỏ trống trong.
  * **Độ dày thép tấm**: **$8.0\text{ mm} = 0.8\text{ cm}$** (đồng bộ chiều dày thành vỏ trống, chống cong vênh nhiệt tối đa).
  * **Lỗ cốt trục xuyên tâm**: $\varnothing 65.0\text{ mm}$ ($R = 32.5\text{ mm}$), xỏ khít vừa vặn qua thân cây láp chính $\varnothing 65\text{ mm}$.
* **Vị trí bố trí dọc trục Y**:
  * Đặt thụt vào trong lòng trống **$5.0\text{ mm}$** so với mép đuôi trống ($Y = +500.5\text{ mm}$):
    * Mặt ngoài đĩa: $Y = +495.5\text{ mm}$.
    * Mặt trong đĩa: $Y = +487.5\text{ mm}$.
  * Mép ngoài ống trống nhô ra $5\text{ mm}$ tạo gờ bảo vệ và rãnh vát chữ V tự nhiên cho đường hàn góc âm.
  * Khoảng hở an toàn đến chóp sau 5 cánh đảo ngoài ($Y = +484.19\text{ mm}$): **$3.31\text{ mm}$** (vận hành quay mượt mà, không va chạm).
* **Kết cấu mối hàn ngấu chịu lực ("Hàn sao cho vừa đủ")**:
  * **Vành hàn cổ trục**: Fillet collar dày $4\text{ mm}$ quanh cốt láp $\varnothing 65\text{ mm}$ ($R = 32.5 \to 38.0\text{ mm}$, $Y = 495.5 \to 499.5\text{ mm}$).
  * **Vành hàn mép chu vi trong**: Fillet seam dày $4\text{ mm}$ bám dọc chu vi trong ống trống ($R = 386.0 \to 392.0\text{ mm}$, $Y = 495.5 \to 499.5\text{ mm}$).
* **Bảo toàn khoảng hở vận hành**:
  * Mép đuôi ống trống vẫn kết thúc tại $Y = +500.5\text{ mm}$.
  * Khoảng hở từ đuôi trống đến mặt trong Mặt Máy Sau ($Y = +600.0\text{ mm}$) giữ **chính xác $99.5\text{ mm} = 9.95\text{ cm}$** theo đúng tiêu chuẩn thông gió lò củi.
* **Đồng bộ chuyển động**: Đĩa đáy sau được hàn dính liền vào cây láp và vỏ trống nên quay đồng bộ 100% khi đảo chiều và đổi tốc độ RPM.

---

## 2. Cây Láp Trục Chính (Trục Bậc Xuyên Tâm Dài 1.3m)
* **Chiều dài tổng thể**: **$1300\text{ mm} = 1.3\text{ m}$** (tăng $10\text{ cm}$ đồng bộ với khoảng cách 2 mặt máy).
* **Thân trục giữa**: $\varnothing 65\text{ mm}$ (Bán kính $R = 32.5\text{ mm}$), dài **$1100\text{ mm} = 110\text{ cm}$** ($Y \in [-500.0, +600.0\text{ mm}]$) xuyên suốt buồng rang giữa 2 mặt máy.
* **Hai đầu tiện bậc lắp bạc đạn & puly**: $\varnothing 60\text{ mm}$, mỗi đầu dài $100\text{ mm} = 10\text{ cm}$:
  * Đầu trước: $Y \in [-600.0, -500.0\text{ mm}]$, nhô ra ngoài Mặt Máy Trước đúng **$82\text{ mm}$**.
  * Đầu sau: $Y \in [+600.0, +700.0\text{ mm}]$, nhô ra ngoài Mặt Máy Sau đúng **$82\text{ mm}$** đối xứng hoàn hảo.

---

## 3. Hệ Thống 10 Cây Chống Tròn Phi 20mm (Xen Kẽ 36 Độ)
* **Vật liệu**: Ống sắt tròn $\varnothing 20\text{ mm}$, rỗng ruột, độ dày thành ống $2\text{ mm}$ ($\varnothing$ trong $16\text{ mm}$).
* **Tầng 1 (5 cây gần đầu miệng trước - $Y = -400\text{ mm}$)**:
  * Cách miệng trước trống $10\text{ cm}$.
  * Bù góc pha $-4.5^\circ \rightarrow$ Các góc: $-4.5^\circ, 67.5^\circ, 139.5^\circ, 211.5^\circ, 283.5^\circ$.
  * Tiếp xúc tiếp tuyến vừa chạm sát sườn mặt bên của 5 cánh ngoài la sắt để hàn liền.
* **Tầng 2 (5 cây ở giữa - $Y = +100\text{ mm}$)**:
  * Cách miệng sau trống $40\text{ cm}$.
  * Các góc: $36^\circ, 108^\circ, 180^\circ, 252^\circ, 324^\circ$.
  * Tiếp xúc tiếp tuyến vừa chạm sát sườn mặt bên của 5 cánh ngoài để hàn liền.
* **Tổng thể**: 10 cây chống tạo thành nan hoa chữ thập lệch pha đều $36^\circ$ quanh chu vi, triệt tiêu biến dạng xoắn vặn của trống khi quay đảo tải nặng.

---

## 4. Hệ Thống 10 Cánh Đảo La Sắt (Trong & Ngoài)
* **5 Cánh Đảo Trong (Nằm ngay giữa thân cây chống)**:
  * Thanh la sắt bản rộng **$10\text{ cm} = 100\text{ mm}$**, dày **$0.8\text{ cm} = 8\text{ mm}$**.
  * Bán kính làm việc: $R = 162\text{ mm} \rightarrow 262\text{ mm}$ (cách mặt cây láp $\approx 13\text{ cm}$ không chạm láp, cách vỏ trống $13\text{ cm}$).
  * Chiều dài dọc trục: **$65\text{ cm} = 650\text{ mm}$** (từ $Y = -400\text{ mm}$ qua tầng chống giữa đến $Y = +250\text{ mm}$).
  * Bước xoắn $P = 1083.3\text{ mm}$, xoắn ngược đúng **$6/10$ vòng ($216^\circ$)**.
  * Nhiệm vụ: Đón dòng hạt rơi từ đỉnh cao và hắt ngược về phía sau, tạo chu trình đối lưu hạt 3D liên tục.
* **5 Cánh Đảo Ngoài (Bám thành trống & chạm cả 10 cây chống để hàn)**:
  * Thanh la sắt bản rộng **$7\text{ cm} = 70\text{ mm}$**, dày **$0.5\text{ cm} = 5\text{ mm}$**.
  * Bán kính làm việc: $R = 322\text{ mm} \rightarrow 392\text{ mm}$ bám sát bề mặt thành trong trống.
  * Chiều dài: $960\text{ mm}$ ($Y = -480\text{ mm} \rightarrow +480\text{ mm}$).
  * Bước xoắn $P = 1600\text{ mm}$, xoắn xuôi đúng **$6/10$ vòng ($216^\circ$)**.
  * Nhiệm vụ: Cào sát thành trống, cuốn và đẩy dòng hạt tịnh tiến xuôi về miệng xả hàng.

---

## 5. Hai Mặt Máy Trước & Sau (Sắt Tấm Dày 1.8cm, Khoảng Cách Lọt Lòng 110cm)
* **Vật liệu**: Sắt tấm kết cấu dày **$1.8\text{ cm} = 18\text{ mm}$** gia công CNC chính xác.
* **Vị trí bố trí dọc trục Y**:
  * **Mặt Máy Trước**: Tọa độ $Y \in [-518.0\text{ mm}, -500.0\text{ mm}]$ (mặt trong tại $Y = -500.0\text{ mm}$).
  * **Mặt Máy Sau**: Tọa độ $Y \in [+600.0\text{ mm}, +618.0\text{ mm}]$ (mặt trong tại $Y = +600.0\text{ mm}$).
  * **Khoảng cách lọt lòng giữa 2 mặt máy**: Đúng **$1100\text{ mm} = 110\text{ cm} = 1.1\text{ m}$** (tăng thêm đúng $10\text{ cm}$ theo yêu cầu).
  * **Phân bố khoảng hở trống bên trong**: Trống dài $100\text{ cm}$ đặt tại $Y = -499.5 \to +500.5\text{ mm}$:
    * Đầu trước áp sát mặt máy trước, chừa khe hở **$0.5\text{ mm}$** chống cạ quẹt khi quay.
    * Mặt sau còn lại đúng **$99.5\text{ mm} = 9.95\text{ cm}$** tạo luồng đối lưu khí nhiệt tuyệt hảo.
* **Hình dáng biên dạng chung**:
  * Phía trên: Cung tròn bán kính $R = 480\text{ mm}$ ($\varnothing 960\text{ mm} = 96\text{ cm}$) bao trọn vỏ ngoài trống ($R = 415\text{ mm}$).
  * Eo thắt: Thắt cong vào tại cao độ $Z = -308.5\text{ mm}$ với bề rộng $73.5\text{ cm}$ ($X = \pm 367.7\text{ mm}$).
  * Chiều cao tổng thể: Giữ nguyên từ đỉnh cung tròn $Z = +480\text{ mm}$ xuống sàn $Z = -850\text{ mm}$ (tổng cao $1330\text{ mm}$).
  * Lỗ tâm trục: Lỗ tròn $\varnothing 65\text{ mm}$ cho đầu cốt láp $\varnothing 60\text{ mm}$ nhô ra $82\text{ mm}$ lắp ổ bi gối đỡ và puly truyền động.
* **Kết cấu chân đồng bộ 2 Mặt Máy Trước & Sau (Phương án C.2 - Vát xéo ra biên + Gờ chân đứng 5.5cm)**:
  * Từ điểm eo thắt ($X = \pm 367.7\text{ mm}, Z = -308.5\text{ mm}$), hai cạnh bên vát chéo một mạch xuôi ra biên ngoài $X = \pm 550\text{ mm}$ tại cao độ $Z = -795\text{ mm}$ (cách mặt sàn/chân máy đúng **$5.5\text{ cm} = 55\text{ mm}$**).
  * Từ điểm $(X = \pm 550\text{ mm}, Z = -795\text{ mm})$, đường biên **bẻ góc vuông thẳng đứng xuống sàn** $Z = -850\text{ mm}$, tạo thành gờ chân đứng cao đúng **$5.5\text{ cm} = 55\text{ mm}$**.
  * Đáy dưới phẳng rộng **$1.1\text{ m} = 1100\text{ mm}$** ($X = \pm 550\text{ mm}$) tiếp xúc phẳng hoàn toàn và êm khít với bệ chân đế máy $111\text{ cm} \times 114.6\text{ cm} \times 0.5\text{ cm}$.
  * Tạo vẻ ngoài đồng bộ, khỏe khoắn, hiện đại và tạo điểm tựa gờ đứng vững chắc cho việc bắt bu-lông/hàn định vị khung bệ máy.

---

## 6. Miệng Ra Hàng & Cụm Máng Xả Hạt Lắp Rời 3 Phần (Góc Tù 120° — Dốc 30° Trong FreeCAD)
* **Vị trí miệng khoét trên mặt máy trước (Sắt 18mm)**:
  * Miệng khoét tại cao độ $Z = -301.9\text{ mm} \rightarrow -201.9\text{ mm}$.
  * Hai bên thành đứng cao **$10\text{ cm} = 100\text{ mm}$** tính từ mép dưới lên.
  * Đỉnh mép trên: Đường thẳng nằm ngang dài **$50\text{ cm} = 500\text{ mm}$** ($X = \pm 250\text{ mm}$).
  * Đáy mép dưới: Đường cong ôm sát chuẩn xác lòng trong của trống ($R = 392\text{ mm}$).
  * Chiều cao thông thủy tại tâm: $19\text{ cm} = 190\text{ mm}$.
* **Cụm máng ra hàng cơ động gồm đúng 3 phần kết cấu (Mô hình hóa 3D Solid 100% trong FreeCAD)**:
  1. **Phần 1: Tấm đáy Inox 1.5mm (`Mieng_Ra_Hang_Day_Inox_1p5mm`)**:
     * **Mép trong giáp trống**: Uốn cong chuẩn xác theo cung tròn $R = 392\text{ mm}$ của phần đáy miệng khoét ($Y = -500.1\text{ mm}$).
     * **Khe hở cách mép quay của vành trống đúng $0.1\text{ mm}$**: Hạt xả trút $100\%$ không bị lọt mép, không kẹt hạt và không bao giờ cạ quẹt vào trống khi quay.
     * **Bẻ góc tù $120^\circ$ chúc dốc xuống đất ($30^\circ$ so với phương ngang)**: Tấm đáy vươn xiên ra ngoài $120\text{ mm}$ (vươn theo phương $Y$ ra $103.92\text{ mm}$ từ $Y = -518.0 \to -621.92\text{ mm}$ và hạ cao độ $60\text{ mm}$ từ $Z = -392.0 \to -452.0\text{ mm}$). Khắc phục triệt để hiện tượng đọng hạt của máng đi ngang; cà phê khi mở cửa sẽ trượt ào ạt rơi tự do thẳng đứng xuống thau làm nguội bên dưới!
     * **Khẩu độ rộng**: **$500\text{ mm}$** ($X = \pm 250\text{ mm}$), thể tích $101,359\text{ mm}^3$.
  2. **Phần 2: Hai tấm Inox vách hông 2 bên (`Mieng_Ra_Hang_2_Vach_Hong_Inox`)**:
     * Dựng đứng ở 2 bên mép máng xả ($X = \pm 250\text{ mm}$), dày $1.5\text{ mm}$, cao $100\text{ mm}$ tại mặt máy và vát xuôi theo độ dốc chúc xuống $30^\circ$ của tấm đáy.
     * Góc trên phía trước được **bo tròn cung lượn mềm mại $R = 30\text{ mm}$ đạt tiếp tuyến $G^1$ mượt mà**: Dẫn hướng dòng hạt, chống văng hạt sang 2 sườn và bảo đảm an toàn tuyệt đối không cấn xước tay người thao tác.
  3. **Phần 3: Hai thanh la gá bắt ốc (`Mieng_Ra_Hang_2_Thanh_La_Bat_Oc` & `Mieng_Ra_Hang_4_BuLong_M8`)**:
     * Thanh la bản rộng **$30\text{ mm}$**, dày **$5\text{ mm}$**, dài **$140\text{ mm}$** hàn liền vào 2 vách hông bên ngoài máng ($X = \pm 250 \to \pm 280\text{ mm}$).
     * Mỗi thanh la **khoan 2 lỗ $\varnothing 10\text{ mm}$** (khoảng cách tâm $70\text{ mm}$) để bắt chặt bằng 4 bu-lông lục giác M8 ren trực tiếp vào mặt máy sắt $18\text{ mm}$.
     * **Ưu điểm cơ khí**: Module lắp rời độc lập bằng 4 con ốc (2 con mỗi bên), tháo lắp cực kỳ nhanh chóng để vệ sinh buồng máy và bảo trì định kỳ.
* **Cánh Cửa Xả Hạt Sắt 18mm & Ô Kính Thạch Anh Quan Sát Phi 10cm (`Cua_Xa_Hat_Sat_18mm` & `O_Kieng_Quan_Sat_Phi_10cm`)**:
  1. **Cánh cửa sắt 18mm (Tái sử dụng phôi cắt từ miệng xả)**:
     * Tận dụng chính tấm phôi sắt dày **$18\text{ mm}$** cắt ra từ miệng khoét mặt máy trước.
     * Thu nhỏ đều **$1.0\text{ mm}$** xung quanh biên dạng (khe hở lọt lòng $1\text{ mm}$ chống kẹt giãn nở nhiệt, bù trừ mạch cắt plasma/CNC):
       * Chiều ngang: Rộng **$498.0\text{ mm}$** ($X \in [-249.0, +249.0\text{ mm}]$ so với miệng $500\text{ mm}$).
       * Mép trên: $Z = -202.93\text{ mm}$ (hạ thấp $1\text{ mm}$ so với ngưỡng mép $Z = -201.93\text{ mm}$).
       * Đáy uốn cong: Bán kính **$R = 391.0\text{ mm}$** (thu nhỏ $1\text{ mm}$ so với lòng trống $R = 392.0\text{ mm}$), đáy tại $Z = -391.0\text{ mm}$.
       * Thể tích: **$1,290,509.79\text{ mm}^3$**.
  2. **Ô kính quan sát thạch anh chịu nhiệt $\varnothing 10\text{ cm}$ nằm chính giữa cửa**:
     * Vị trí tâm lỗ: Tọa độ **$(X = 0, Z = -296.97\text{ mm})$** — nằm ngay trọng tâm hình học của cánh cửa xả (cách mép trên $94.0\text{ mm}$, cách đáy cong $94.0\text{ mm}$, cách 2 mép bên $249.0\text{ mm}$).
     * Đĩa kính thạch anh chịu nhiệt độ cao ($> 800^\circ\text{C}$): Đường kính **$\varnothing 100\text{ mm} = 10\text{ cm}$**, độ dày **$8\text{ mm}$**, đặt âm chính giữa chiều dày $18\text{ mm}$ của cánh cửa sắt.
     * Độ trong suốt hiển thị: $65\%$, màu lam thạch anh trong trẻo `(0.72, 0.92, 0.96)`. Giúp người thợ rang theo dõi trực tiếp chuyển động cuộn và sắc độ ngả màu của mẻ cà phê/hạt nông sản mà không cần hé mở cửa xả.
  3. **Vành Inox 304 giữ kính & 4 Vít chìm M5**:
     * Mặt bích vành tròn Inox 304 dày $3\text{ mm}$, đường kính ngoài $\varnothing 124\text{ mm}$, lỗ thông quan sát $\varnothing 92\text{ mm}$ giữ ngàm viền kính $4\text{ mm}$ xung quanh kèm gioăng chịu nhiệt.
     * Cố định bằng 4 vít chìm Inox M5 phân bố đều ở góc $45^\circ, 135^\circ, 225^\circ, 315^\circ$ trên đường tròn định vị $\varnothing 108\text{ mm}$.
  4. **Cơ cấu trục láp Ø30mm dài 100cm bẻ cần gạt 30cm sang bên TRÁI & 2 Khâu nối đôi cân bằng 2 bên (Dài 8cm, Rộng 3cm)**:
     * **Cây láp tròn đặc $\varnothing 30\text{ mm}$ (Thép C45)**:
        * Tổng chiều dài phôi: **$100\text{ cm} = 1000\text{ mm}$**.
        * Thân trục ngang: Dài **$70\text{ cm} = 700\text{ mm}$** ($X = +350.0 \to -350.0\text{ mm}$), đầu bên PHẢI có vành chặn cốt collar $\varnothing 45\text{ mm} \times 12\text{ mm}$.
        * **Cần gạt bẻ cong sang BÊN TRÁI NGHIÊNG 45° CHĨA RA PHÍA TRƯỚC**: Bán kính uốn $R = 45\text{ mm}$ tại đầu bên TRÁI ($X = -350\text{ mm}$), cần gạt dài $30\text{ cm} = 300\text{ mm}$ chúc xuống dưới và xoay nghiêng đúng **$45^\circ$ chĩa ra phía trước** ($Y \in [-543.0, -755.1\text{ mm}]$, $Z \in [-171.93, -384.1\text{ mm}]$), đầu cần gắn núm cầu tay nắm $\varnothing 42\text{ mm}$ đầm chắc, cực kỳ thuận tay cho người vận hành đứng trước máy kéo mở cửa xả hạt.
        * Cao độ lắp đặt: Nằm cao hơn mép trên miệng xả đúng **$3\text{ cm} = 30\text{ mm}$** (tọa độ tâm trục $Z = -171.93\text{ mm}$).
        * Khoảng cách trục so với mặt máy: Bề mặt ngoài cây láp cách mặt máy đúng **$1\text{ cm} = 10\text{ mm}$**, tâm trục đặt tại $Y = -543.0\text{ mm}$ ($Y_{\text{mat}} - 10 - 15\text{ mm}$).
     * **2 Gối đỡ bạc đạn rùa UCP206 (Cốt $\varnothing 30\text{ mm}$)**:
       * Vỏ gang đúc hình mai rùa, vòng bi cầu tự lựa 2 nắp chắn bụi, vú mỡ bôi trơn M8 trên đỉnh.
       * Vị trí lắp đặt: Đặt tại $X = \pm 310.0\text{ mm}$ (mép gối đỡ cách mép ngoài máng xả đúng **$1\text{ cm} = 10\text{ mm}$**).
       * Chân đế gối dày $16\text{ mm}$ áp sát mặt máy sắt 18mm, thân gối ôm trọn cây láp tại $Y = -543.0\text{ mm}$.
     * **4 Bu-lông gá M14**:
       * Mỗi bên 2 bu-lông lục giác M14 xuyên qua chân gối, cắm ren ngấu sâu vào mặt máy trước.
     * **2 Khâu nối đôi cân bằng 2 bên (`Hai_Khau_Noi_Cua_Xa_8cm`)**:
       * **Vị trí bố trí đối xứng**: Đặt tại $X = -130.0\text{ mm}$ (Bên Trái) và $X = +130.0\text{ mm}$ (Bên Phải), cách đều tâm máy, hoàn toàn không che khuất ô kính quan sát $\varnothing 10\text{ cm}$ ở giữa ($X \in [-62, +62\text{ mm}]$), tạo lực nâng/hạ cửa xả cân bằng tuyệt đối 2 bên.
       * **2 Nhẫn tròn ôm cây láp**: Chiều dài $L = 3\text{ cm} = 30\text{ mm}$ dọc theo trục X, dày $10\text{ mm}$ ($ID = 30\text{ mm}, OD = 50\text{ mm}$), có lỗ ren vít chí M8 trên đỉnh khóa chặt vào cây láp. Mép sau của nhẫn tròn nằm tại $Y = -518.0\text{ mm}$, trùng khít với mặt máy.
       * **2 Tấm hình chữ nhật đầu nửa tròn**:
         * Chiều dài: **$L = 8\text{ cm} = 80\text{ mm}$** (chuẩn mới theo trục đứng Z từ $Z = -171.93 \to -251.93\text{ mm}$).
         * Chiều rộng: $W = 3\text{ cm} = 30\text{ mm}$ (bằng chiều dài nhẫn tròn).
         * Bề dày: $T = 10\text{ mm}$ (vừa khít khoảng hở 10mm từ cây láp đến mặt máy).
         * **Mặt lưng áp sát mặt máy**: Toàn bộ mặt lưng phẳng của tấm **ÁP SÁT 100% VÀO MẶT MÁY VÀ CÁNH CỬA XẢ SẮT 18MM** tại $Y = -518.0\text{ mm}$ khi cửa đóng kín (phẳng đứng theo trục Z từ $Z = -171.93 \to -251.93\text{ mm}$).
         * Đầu dưới bo nửa tròn bán kính $R = 15\text{ mm}$ ($\varnothing 30\text{ mm}$), tâm nửa tròn khoan lỗ xỏ chốt Pin $\varnothing 10\text{ mm}$ tại cao độ $Z = -236.93\text{ mm}$ (cách mép trên cửa xả $34\text{ mm} = 3.4\text{ cm}$, tạo thế đòn bẩy chắc chắn).
     * **2 Bu-lông Chốt Pin M10 & Ê-cu tự hãm (`Hai_Chot_Pin_M10_Cua_Xa`)**:
       * Bu-lông chốt phi 10mm bắt qua lỗ đầu nửa tròn liên kết chặt khâu nối vào cánh cửa xả sắt 18mm.
     * **Tay khóa gài chữ L bên phải (`Tay_Khoa_Gai_Cua_Xa`)**:
       * Then xoay trục $\varnothing 16\text{ mm}$ tại $X = +229\text{ mm}$, ép tì chặt cánh cửa xả vào mặt máy khi đóng.

---

## 7. Cây Thăm Hàng (Trier / Sampler) & Lỗ Thăm Phi 30mm
* **Lỗ thăm**: Hình tròn $\varnothing 30\text{ mm}$ nằm trên mặt máy trước, ngang cao độ cây láp bên trái ($X = -200\text{ mm}, Z = 0\text{ mm}$).
* **Cây thăm hạt Inox**:
  * Ống inox $\varnothing 28\text{ mm}$, dài $45\text{ cm}$, tay cầm gỗ phi $34\text{ mm}$ dài $12\text{ cm}$.
  * Góc xiên: Nằm ngang cao độ cốt láp ($Z = 0$), xiên góc $16.7^\circ$ hướng vào tâm.
  * Vị trí mũi thăm: Dừng tại $Y = -427.6\text{ mm}$.
  * Khoảng hở an toàn: Cách cánh ngoài $14.6\text{ cm}$, cách cây chống $1.8\text{ cm}$, cách cánh trong $2.8\text{ cm}$, cách cốt láp $14.3\text{ cm}$ $\rightarrow$ **Tuyệt đối không cấn cánh đảo hay cây chống khi máy đang quay!**

---

## 8. Cửa Buồng Đốt Mặt Sau & 2 Bản Lề Cối Mở 120 Độ
* **Lỗ khoét mặt máy sau**: Kích thước dài **$50\text{ cm}$** $\times$ cao **$30\text{ cm}$** ($X \in [-250, +250\text{ mm}]$, $Z \in [-800, -500\text{ mm}]$), cách chân máy đúng **$5\text{ cm}$**, đặt tại mặt máy sau mới ($Y = +600 \to +618\text{ mm}$).
* **Cánh cửa sắt 18mm**: Sử dụng lại chính phôi sắt tấm dày $1.8\text{ cm}$ cắt ra (kích thước $49.8\text{ cm} \times 29.8\text{ cm}$, khe cắt CNC $1\text{ mm}$, đặt tại $Y = +600 \to +618\text{ mm}$).
* **2 Bản lề cối chịu lực**: Hàn cố định bên trái mép cửa (nhìn từ sau: $X = +249.5\text{ mm}, Y = +618\text{ mm}$), cối phi $20\text{ mm}$, đệm long đền đồng, tâm xoay tại $Y = +626\text{ mm}$.
* **Góc mở cửa**: **Mở rộng $120^\circ$ về bên trái**, xoay áp sát sườn máy, giải phóng $100\%$ miệng buồng đốt cho thao tác nạp củi lớn và cào tro xỉ trơn tru.
* **Tay khóa**: Then gài dạng chữ L (L-handle) bố trí bên phải cửa kèm núm xoay cách nhiệt.

---

## 9. Buồng Đốt Củi Gạch Sa Mốt Nằm Gọn Dưới Trống (Dài 110cm)
* **Quy cách viên gạch sa mốt**: $30\text{ cm} \times 10\text{ cm} \times 5\text{ cm}$ (Dài $\times$ Rộng $\times$ Dày), mạch vữa xây chịu nhiệt $1.5\text{ mm}$.
* **Sàn đáy buồng đốt**:
  * Lát 7 hàng gạch nằm dày **$5\text{ cm}$** ($Z = -850 \rightarrow -800\text{ mm}$).
  * Kích thước sàn: Rộng **$70\text{ cm}$** ($X = \pm 350\text{ mm}$), Dài **$110\text{ cm} = 1.1\text{ m}$** ($Y \in [-500.0, +600.0\text{ mm}]$) ôm kín khít từ Mặt Máy Trước đến Mặt Máy Sau.
  * Bằng phẳng khít ngang ngưỡng mép dưới cửa sau ($Z = -800\text{ mm}$).
* **Hai vách hông lò**:
  * Bao **đúng 1 lớp gạch nằm** dày **$10\text{ cm}$** mỗi bên: Vách trái ($X = -350 \rightarrow -250\text{ mm}$), Vách phải ($X = +250 \rightarrow +350\text{ mm}$).
  * Chiều dài vách hông: **$110\text{ cm}$** ($Y = -500 \rightarrow +600\text{ mm}$).
  * Lòng trong thông thủy buồng đốt: Rộng đúng **$50\text{ cm}$** ($X = \pm 250\text{ mm}$) khớp chuẩn với cửa sau $50\text{ cm}$.
  * Tổng bề rộng lò gạch phủ bì: Đúng **$70\text{ cm}$**, lọt hoàn toàn trong eo thắt mặt máy ($73.5\text{ cm}$), dư an toàn $1.8\text{ cm}$ mỗi bên $\rightarrow$ **Nằm gọn lọt thỏm dưới gầm trống, không hề bị lòi ra ngoài**.
  * Chiều cao vách: Xây **9 hàng gạch** ($45\text{ cm}$ từ sàn lò, tổng cao $50\text{ cm}$ từ chân máy) lên tới cao độ **$Z = -350\text{ mm}$ vừa chạm tới đáy trống**.
  * Cưa gọt vòm cong $R_{\text{cut}} = 425\text{ mm}$ ôm cách vỏ áo ngoài ($R_{\text{ao}} = 415\text{ mm}$) đúng **$1\text{ cm} = 10\text{ mm}$** đồng đều giữ nhiệt tuyệt đối.
* **Vách chắn trước**: Dày $10\text{ cm}$, rộng $50\text{ cm}$, cao 8 lớp (đến $Z = -400\text{ mm}$), gọt vòm $R425\text{ mm}$ cách trống $1\text{ cm}$, nằm hoàn toàn dưới miệng xả hạt.

---

## 10. Chân Đế Máy Hình Chữ Nhật (Sắt Tấm Dày 0.5cm, 111cm x 114.6cm)
* **Vật liệu**: Thép tấm dày **$0.5\text{ cm} = 5\text{ mm}$**.
* **Kích thước mặt bằng**: **$1110\text{ mm} \times 1146\text{ mm}$** ($111\text{ cm} \times 114.6\text{ cm}$).
* **Độ dư tiêu chuẩn**: Dư mỗi bên trước sau đúng **$0.5\text{ cm} = 5\text{ mm}$** ($Y \in [-523.0, +623.0\text{ mm}]$ so với 2 mặt máy tại $Y = -518\text{ mm}$ và $Y = +618\text{ mm}$) và trái phải đúng **$0.5\text{ cm} = 5\text{ mm}$** ($X \in [-555.0, +555.0\text{ mm}]$).
* **Vị trí**: Đặt phẳng dưới mặt sàn xưởng tại $Z = -855\text{ mm} \rightarrow -850\text{ mm}$, đỡ trọn chân 2 mặt máy và lò gạch, liên kết chống rung lật tuyệt đối.

---

## 11. Hộp Vô Hàng Inox 3mm & Cơ Cấu Van Gạt Láp Ø20mm (Tab 2)
* **Kiểu dáng**: Hình thang vuông dựng đứng, đầu nhọn dốc hướng xuống đáy trước ($Z = 0$).
  * **Kích thước mặt bằng**: Đáy vuông $30\text{ cm} \times 30\text{ cm}$, vách trước cao $65\text{ cm}$, vách sau cao $30\text{ cm}$ (từ $Z = 35\text{ cm} \rightarrow 65\text{ cm}$).
  * **Máng trượt dốc**: Tấm inox $300 \times 461\text{ mm}$, nghiêng $49.4^\circ$ giúp hạt cà phê trôi tự nhiên không đọng góc.
  * **Thể tích buồng chứa**: $\sim 62.6\text{ Lít}$ ($\sim 25 - 35\text{ kg}$ hạt cà phê nhân tươi).
* **Cửa xả & Cửa nạp**:
  * **Cửa xả hạt đáy trước**: Khoảng trống $20\text{ cm} \times 30\text{ cm}$ ở phía dưới chân vách trước ($Z = 0 \rightarrow 200\text{ mm}$).
  * **Lỗ khoét tròn $\varnothing 20\text{ cm}$ vách trước**: Khoét ở phần trên của tấm vách trước, mép trên chừa lại đúng $1\text{ cm} = 10\text{ mm}$.
  * **Lỗ nắp đỉnh $\varnothing 20\text{ cm}$**: Khoét chính giữa tấm nắp đỉnh vuông $30\text{ cm} \times 30\text{ cm}$ tại $Z = 650\text{ mm}$.
* **Ống nạp liệu $\varnothing 19.9\text{ cm}$ dài $30\text{ cm}$**:
  * Đặt từ nắp đỉnh ($Z = 650\text{ mm}$) đâm thẳng xuống ($Z = 350\text{ mm}$).
  * Khe hở lọt lỗ: $0.5\text{ mm}$ đều quanh chu vi lỗ $\varnothing 200\text{ mm}$.
  * **Trục xoay láp tròn đặc $\varnothing 20\text{ mm}$**: Dài $428\text{ mm}$, xuyên qua 2 lỗ tròn $\varnothing 20\text{ mm}$ tại $(X = 10.5, Z = 353.9\text{ mm})$, **dư nhô dài ra đúng $10\text{ cm} = 100\text{ mm}$ về bên phải** (mặt ngoài hông phải $Y = +153\text{ mm} \rightarrow +253\text{ mm}$) để gắn cần gạt và tay nắm thao tác.
  * **Hệ thống 4 vòng tròn bạc chặn (Mỗi bên 2 vòng, ID $\varnothing 20\text{ mm}$ vừa khít cây láp, OD $\varnothing 32\text{ mm}$ thành dày 6mm)**:
    - **Vòng dày ($10\text{ mm}$) hàn vào hộp**: Hàn dính cố định vào mặt ngoài 2 tấm hông hộp, làm gối bạc trượt tăng cứng vững và chống mài mòn cho lỗ thành hộp.
    - **Vòng ngoài ($8\text{ mm}$) hàn vào cây láp**: Hàn dính trực tiếp vào cây láp $\varnothing 20\text{ mm}$, đóng vai trò cữ chặn định vị chống trượt dọc trục (axial stop) và xoay đồng bộ cùng cây láp khi đóng mở van.
  * **Lá van inox 3mm**: Đúng **1 tấm Inox 304 dày 3mm bo tròn đẹp mắt** ($W = 220\text{ mm}$, dài $249.5\text{ mm}$ từ tim láp đến đỉnh, đầu trước uốn cong bán nguyệt $R = 110\text{ mm}$ đồng tâm hoàn hảo với ống $\varnothing 19.9\text{ cm}$, chừa mép đều $10.5\text{ mm}$ xung quanh không còn góc nhọn thừa) hàn cố định trực tiếp vào trục láp tròn $\varnothing 20\text{ mm}$.
  * **Cơ cấu góc tọa độ 3 góc vuông (1 Ra Ngoài, 1 Xuống Dưới - 3 cây láp tròn Ø20mm trực giao tại đầu láp nhô ra)**:
    - **Vị trí gốc tọa độ**: Nằm ngay chỗ giao vuông góc ở đầu cây láp nhô ra $10\text{ cm}$ bên sườn máy tại $(X = -240, Y = -807.5, Z = 508.9\text{ mm})$.
    - **3 Trục trực giao tạo đúng 3 góc vuông tuyệt đối ($90^\circ$)**:
      1. **Trục láp ngang Ø20mm**: Dài $428\text{ mm}$, là trục xoay chính của cụm van gạt (trên máy nằm ngang sườn tại $X = -240\text{ mm}$, nhô ra $10\text{ cm}$).
      2. **Cây vuông góc 1 (Cần ngang Ø20mm quay ra ngoài)**: Dài $220\text{ mm}$ ($22\text{ cm}$), vươn ngang ra phía ngoài (hướng $-Y$ trên máy rang từ $Y = -807.5 \to -1027.5\text{ mm}$, hướng thẳng về phía người vận hành đứng trước máy).
      3. **Cây vuông góc 2 (Cần đứng Ø20mm quay xuống dưới)**: Dài $220\text{ mm}$ ($22\text{ cm}$), chúc thẳng đứng xuống dưới $-Z$ ($Z = 508.9 \to 288.9\text{ mm}$ trên máy), vuông góc tuyệt đối với cây láp ngang và cần gạt ngoài.
    - **Cặp góc vuông hình thành**:
      - Góc 1: Trục Láp $\perp$ Cần Ra Ngoài ($90^\circ$).
      - Góc 2: Cần Ra Ngoài $\perp$ Cần Chúc Xuống ($90^\circ$).
      - Góc 3: Cần Chúc Xuống $\perp$ Trục Láp ($90^\circ$).
      $\rightarrow$ Tạo thành khung **3 góc vuông: 1 ra ngoài, 1 chúc xuống**, cực kỳ thẩm mỹ, gọn gàng, đầm chắc, hạ thấp trọng tâm cụm điều khiển và cho phép người vận hành chọn 2 cách thao tác (nâng cần ngoài lên hoặc kéo cần dưới về phía mình).
  * **Góc vận hành**: $0^\circ$ (đóng kín chặn đáy ống) $\rightarrow 45^\circ$ (mở thông hạt trôi xuống trống rang).
* **Bảng điều khiển tích hợp 2 Tab GUI (Dual-Tab Controller)**:
  * **Tab 1: 🏭 Máy Rang Củi (Trống 2 Lớp)**: Tốc độ quay $5 - 120\text{ RPM}$, đảo chiều, tạm dừng, xuyên thấu vỏ trống, ẩn/hiện vỏ trống, bệ đế, lò gạch sa mốt, nút Ẩn/Hiện Hộp Vô Hàng Mặt Trước, mở cửa sau $120^\circ$, đổi tư thế đứng/ngang, góc nhìn Isometric/Sau/Trước.
  * **Tab 2: 📥 Hộp Vô Hàng & Van Gạt (Ống Ø20)**: Điều khiển góc mở van gạt live ($0^\circ \rightarrow 45^\circ$), nút đóng/mở 1-click, **nút Ẩn/Hiện thùng bên ngoài** (ẩn toàn bộ các tấm vỏ ngoài để nhìn rõ ống nạp và van gạt như ẩn vỏ trống), xuyên thấu vỏ hộp, mở/đậy nắp đỉnh, ẩn/hiện khối tham chiếu, góc nhìn nhanh (Isometric, Cạnh, Mặt Trước) và Bảng kê cắt phôi Inox 3mm (BOM).
  * **Đồng bộ FreeCAD 3D View**: Tự động kích hoạt đúng tài liệu 3D tương ứng khi người dùng click chuyển tab trên giao diện điều khiển.

---

## 12. Lỗ Nạp Liệu Chữ Nhật 20x30cm Đẩy Lên Cao Tối Đa Trên Mặt Máy Trước & Máng Dẫn Hướng Chống Rớt Hạt
* **Khôi phục Mặt Máy Sau ($Y = +500 \to +518\text{ mm}$)**:
  * Loại bỏ hoàn toàn lỗ nạp phía sau, mặt máy sau nguyên bản phẳng liền khối ở nửa trên, chỉ giữ lại lỗ cốt tâm $\varnothing 65\text{ mm}$ và cửa buồng đốt $50\times 30\text{ cm}$ phía dưới.
* **Lỗ khoét chữ nhật $20\text{ cm} \times 30\text{ cm}$ trên Mặt Máy Trước ($Y = -518 \rightarrow -500\text{ mm}$) — Tối Ưu Lên Cao Nhất Có Thể**:
  * **Chiều ngang (trục X)**: $W = 300\text{ mm} = 30\text{ cm}$ ($X \in [-150.0, +150.0\text{ mm}]$ đối xứng qua trục tâm máy).
  * **Chiều cao (trục Z)**: $H = 200\text{ mm} = 20\text{ cm}$ ($Z \in [+155.0\text{ mm}, +355.0\text{ mm}]$ — nâng cao lên sát kịch trần vòm trống).
  * **Kiểm tra lọt lòng đường tròn trống ($R_{\text{in}} = 392\text{ mm}$)**:
    - Tại 2 góc trên cùng ($X = \pm 150\text{ mm}, Z = 355\text{ mm}$):
      $$R_{\text{góc}} = \sqrt{150^2 + 355^2} \approx 385.39\text{ mm} < R_{\text{in}} = 392.0\text{ mm}$$
    - Chừa lại đúng **$6.61\text{ mm}$** thành sắt dày dặn so với mép trong trống, vừa vặn tuyệt đối không lẹm vào thành trống, vừa đạt độ cao tối đa về mặt hình học!
    - Ngưỡng đáy lỗ nâng lên cao độ $Z = +155\text{ mm}$, cách đỉnh cốt trục giữa ($\varnothing 65\text{ mm}$) tới **$122.5\text{ mm} = 12.25\text{ cm}$** (khoảng không gian cực kỳ thoáng đãng).
    - Cách miệng ra hàng phía dưới ($Z \le -202\text{ mm}$) hơn **$35.7\text{ cm}$** và không chạm lỗ cắm que thăm hàng ($X = -200\text{ mm}, Z = 0$).
* **Máng trượt dẫn hướng Inox 304 đâm sâu vào lòng trống từ Mặt Trước (Độ Dốc Cực Đại $50.6^\circ$)**:
  * **Vượt qua khe hở quay $2\text{ mm}$**: Máng trượt đâm xuyên qua tấm mặt máy trước dày $1.8\text{ cm}$ và **vươn sâu $60\text{ mm}$ vào lòng trống** (tới $Y = -440\text{ mm}$), triệt tiêu hoàn toàn nguy cơ hạt rơi vào khe hở giữa mép trống và mặt máy.
  * **Độ dốc trượt cực đại $\alpha = 50.6^\circ$**: Nhờ nâng lỗ nạp lên cao nhất ($Z_{\text{bot}} = +155\text{ mm}$), sàn máng nghiêng dốc từ $Z = +155\text{ mm}$ ($Y = -518$) xuống $Z = +60\text{ mm}$ ($Y = -440$), tạo góc dốc **$50.6^\circ$** (tương đương độ dốc thành phễu $49.4^\circ$). Cà phê nhân trượt xả lao như thác cuốn vào sâu trong lòng trống, không bao giờ lo đọng hạt.
  * **2 Thành be chắn hai bên (Side Baffles)**: Cao $60\text{ mm}$ ($Z \in [155, 215\text{ mm}]$), ngăn tuyệt đối không cho hạt bị văng tạt sang hai bên khi gặp luồng khí nóng đối lưu.
* **Gắn cụm Hộp Vô Hàng Inox 3mm vào Mặt Trước Máy Rang**:
  * Cửa xả hạt đáy $20\times 30\text{ cm}$ của Hộp Vô Hàng khớp kín khít $100\%$ với cửa nạp liệu trên mặt máy trước tại cao độ tối ưu $Z = 155 \rightarrow 355\text{ mm}$, vị trí $Y \in [-818.0, -518.0\text{ mm}]$.
  * Đỉnh nắp hộp vươn lên cao độ $Z = +805\text{ mm} \approx 80.5\text{ cm}$, đứng đổ bao hạt ngay trước máy vô cùng thuận tiện, không cần đi vòng ra sau.
  * Cụm tay gạt 3 góc vuông $\varnothing 20\text{ mm}$ (1 ra ngoài, 1 chúc xuống) hướng trực diện về phía người vận hành, thao tác nâng/kéo mở $0^\circ \to 45^\circ$ cực kỳ nhẹ nhàng, đồng bộ live trên cả 2 Tab mô hình 3D.

---

## 13. Cụm Cây Láp Tròn Phi 30mm Dài 100cm Bẻ Cần Gạt Sang Trái 30cm Nghiêng 45° Ra Trước & 2 Gối Đỡ Bạc Đạn Rùa UCP206
* **Cây láp tròn đặc $\varnothing 30\text{ mm}$**:
  * **Tổng chiều dài phôi**: $100\text{ cm} = 1000\text{ mm}$.
  * **Thân trục ngang**: Dài $70\text{ cm} = 700\text{ mm}$ ($X \in [-350.0, +350.0\text{ mm}]$).
  * **Cần gạt bẻ cong sang bên TRÁI nghiêng 45° chĩa ra trước**: Tại $X = -350.0\text{ mm}$, uốn bán kính lượn $R = 45\text{ mm}$, cần gạt vươn dài $30\text{ cm} = 300\text{ mm}$ chúc xuống dưới và xoay nghiêng đúng **$45^\circ$ chĩa ra phía ngoài** ($Y \in [-543.0, -755.1\text{ mm}]$, $Z \in [-171.93, -384.1\text{ mm}]$), gắn núm cầu kim loại $\varnothing 42\text{ mm}$ cầm nắm công thái học.
  * **Vòng chặn định vị bên phải**: Vòng chặn $\varnothing 45\text{ mm}$, dày $12\text{ mm}$ tại đầu phải $X = +350\text{ mm}$ khóa chống dịch chuyển dọc trục.
* **Vị trí lắp ráp**:
  * **Cao hơn mép trên miệng xả đúng $3\text{ cm} = 30\text{ mm}$**: Cao độ tâm trục $Z_{\text{shaft}} = -171.93\text{ mm}$ (mép trên miệng xả ở $Z = -201.93\text{ mm}$).
  * **Tọa độ trục $Y$**: $Y_{\text{shaft}} = -543.0\text{ mm}$ (khoảng hở từ bề mặt cây láp đến mặt máy trước đúng $1\text{ cm} = 10\text{ mm}$).
* **2 Gối đỡ bạc đạn rùa UCP206 cốt $\varnothing 30\text{ mm}$**:
  * **Vị trí**: Đặt tại $X = \pm 310\text{ mm}$ (cách mép ngoài thanh la máng xả $1\text{ cm}$).
  * **Tấm đệm sắt kê chân gối dày đúng $1\text{ cm} = 10\text{ mm}$**: Kê giữa mặt máy sắt 18mm và chân gối đỡ gang UCP206 để đưa tâm trục ra đúng khoảng cách vận hành.
  * **Bu-lông gá**: 4 bu-lông M14 cắm ren vào mặt máy sắt 18mm.
* **Cánh cửa xả sắt 18mm có ô kính quan sát $\varnothing 10\text{ cm}$**:
  * Cắt từ phôi mặt máy thu nhỏ $1\text{ mm}$ đều 4 cạnh: Rộng $398\text{ mm}$, Cao $198\text{ mm}$, Dày $18\text{ mm}$.
  * Ô kính thạch anh chịu nhiệt $\varnothing 100\text{ mm}$ dày $8\text{ mm}$ nằm chính giữa cánh cửa.
  * Vành Inox 304 kẹp giữ kính và 4 vít chìm M5.
  * Cụm tay khóa then gài L bên phải ($X = +229\text{ mm}$) giữ cửa đóng kín khít.

---

## 14. Tích Hợp Trực Tiếp 2 Khâu Nối Đôi Cân Bằng Cửa Xả Vào Mô Hình Chính (`Hai_Khau_Noi_Cua_Xa_8cm`)
* **Tích hợp mô hình & Dọn dẹp macro phụ**:
  * Đã tích hợp trực tiếp và đồng bộ 100% vào **4 tệp mô hình máy chính**: `mo_phong_may_rang_cui.py`, `mo_phong_may_rang_cui.FCMacro`, `trong_hinh_tru.py`, `trong_hinh_tru.FCMacro`.
  * Đã **xóa bỏ hoàn toàn** các tệp macro phụ tạm thời (`macro_thiet_ke_khau_noi_cua_xa.*`) theo yêu cầu, đảm bảo cấu trúc dự án tinh gọn, tập trung duy nhất vào file mô hình hoàn chỉnh.
* **Kích thước hình học chuẩn của Khâu nối đôi cân bằng (Dài mặc định 8cm, ÁP SÁT MẶT MÁY 100%)**:
  1. **2 Nhẫn tròn ôm cây láp $\varnothing 30\text{ mm}$**:
     * Đường kính trong: $ID = 30\text{ mm}$ (vừa khít cây láp tròn $\varnothing 30\text{ mm}$).
     * Bề dày thành nhẫn: $T = 10\text{ mm} \rightarrow$ Đường kính ngoài $OD = 50\text{ mm}$.
     * Chiều dài nhẫn: $L = 30\text{ mm}$ (đúng $3\text{ cm}$ dọc theo chiều trục láp X).
     * Có lỗ ren vít chí M8 trên đỉnh nhẫn siết chặt khóa then vào cây láp.
     * Mép sau cùng của nhẫn tròn: Nằm tại $Y = -518.0\text{ mm}$, phẳng khít với mặt máy trước.
  2. **2 Tấm hình chữ nhật đầu nửa tròn (Dài 8cm, Áp sát mặt máy)**:
     * Kích thước: Rộng $3\text{ cm} = 30\text{ mm}$ (bằng chiều dài nhẫn), Dài **$8\text{ cm} = 80\text{ mm}$** (chuẩn mới theo trục đứng Z từ $Z = -171.93 \to -251.93\text{ mm}$), Dày $10\text{ mm}$ (vừa khít khoảng hở 10mm từ cây láp đến mặt máy).
     * **Mặt lưng áp sát mặt máy**: Toàn bộ mặt lưng phẳng của tấm **ÁP SÁT 100% VÀO MẶT MÁY VÀ CÁNH CỬA XẢ SẮT 18MM** tại $Y = -518.0\text{ mm}$ khi cửa đóng kín. Mặt trước tại $Y = -528.0\text{ mm}$ tiếp xúc phẳng khít với bề mặt cây láp.
     * Đầu dưới bo tròn hình bán nguyệt: Bán kính $R = 15\text{ mm}$ (đường kính ngoài $30\text{ mm}$).
     * Khoan lỗ chốt xoay ở tâm nửa tròn: Đường kính $\varnothing 10\text{ mm}$ dùng cho bu-lông / chốt Pin M10 tại $Z = -236.93\text{ mm}$ (cách mép trên cánh cửa xả $34\text{ mm} = 3.4\text{ cm}$, truyền lực đòn bẩy vững chắc).
  3. **Nhân bản thành 2 bên cân bằng đối xứng ($X = \pm 130\text{ mm}$)**:
     * **Vị trí bố trí**: Đặt cân xứng tại $X = -130.0\text{ mm}$ (Bên Trái) và $X = +130.0\text{ mm}$ (Bên Phải), cách đều tâm máy.
     * **Bảo vệ ô kính quan sát**: Ô kính thạch anh tròn $\varnothing 10\text{ cm}$ ở giữa cửa xả ($X \in [-62, +62\text{ mm}]$) hoàn toàn thông thoáng, mỗi khâu nối cách mép kính tới $68\text{ mm}$, tầm nhìn không bị cản trở.
     * **Cân bằng động lực học**: Khi người vận hành gạt cần 30cm bên trái, lực kéo/ép được truyền đồng thời qua 2 cánh tay đòn song song, triệt tiêu hoàn toàn momen vặn vẹo cánh cửa sắt 18mm nặng và phân bố áp lực đóng kín đều trên toàn bộ gioăng miệng xả.
  4. **2 Chốt Pin M10 & Ê-cu tự hãm (`Hai_Chot_Pin_M10_Cua_Xa`)**:
     * 2 Bu-lông chốt phi 10mm xuyên qua lỗ đầu nửa tròn bắt trực tiếp vào cánh cửa xả sắt 18mm, giữ chặt khâu nối áp khít cánh cửa vào mặt máy khi đóng.

---

## 15. Bộ Chỉnh Gối Bi Trục Phi 60mm - Kiểu Phương Ân (Thiết Kế Chi Tiết Chuẩn 100%)

### 15.1. Khái Niệm & Vai Trò Thực Tế Của Bộ Chỉnh Máy Rang
* **Bộ chỉnh máy rang** là cụm cơ cấu định vị cơ khí chính xác dọc theo trục quay ($Y$), bắt trực tiếp vào mặt máy trước/sau bằng 4 bu-lông lớn:
  1. **Căn chỉnh khe hở nhiệt độ & chống cạ quẹt**: Giữ khe hở đầu trước giữa vành trống và mặt máy trước đúng chuẩn **$0.5\text{ mm}$**, không để trống bị bó kẹt khi giãn nở vì nhiệt ở $250^\circ\text{C} - 300^\circ\text{C}$ và triệt tiêu nguy cơ cạ kim loại làm mòn thành trống hoặc rớt hạt cà phê.
  2. **Bù trừ độ rơ dọc trục & căn chỉnh đồng trục**: Khi lắp ráp thực tế, dung sai cơ khí của mối hàn bệ máy và thân vỏ có thể sai lệch. Bộ chỉnh cho phép người thợ vặn nhẹ cổ siết lục giác $S=105\text{ mm}$ để dịch chuyển ổ bi tịnh tiến mượt mà $\pm 15\text{ mm}$ dọc trục.
  3. **Khóa chống rung cực nhanh (Quick-Lock Clamp)**: Cần gạt công thái học tại góc $-150^\circ$ siết chặt rãnh kẹp ôm cổ ren, triệt tiêu hoàn toàn hiện tượng rung lắc và tự tháo lỏng ốc khi máy chạy liên tục $40\text{ RPM}$.
  4. **Đỡ tải trọng tâm trống rang**: Chịu toàn bộ tải trọng tĩnh của trống ($>150\text{ kg}$) cộng thêm $30 - 60\text{ kg}$ hạt cà phê khi rang và lực quán tính quay.
  5. **Kín bụi tuyệt đối**: Bịt kín đầu cốt trục láp $\varnothing 60\text{ mm}$ bằng nắp tròn $\varnothing 86\text{ mm}$ và 3 vít M4, ngăn $100\%$ vỏ lụa và bụi cà phê lọt vào phá hỏng bạc đạn.

---

### 15.2. Danh Mục 7 Chi Tiết Cấu Tạo Bộ Chỉnh (BOM Chuẩn Thực Tế)

| STT | Mã Chi Tiết | Tên Chi Tiết | Quy Cách Kỹ Thuật & Kích Thước | Vật Liệu Chế Tạo |
| :---: | :--- | :--- | :--- | :--- |
| **1** | `1_Than_Goi_Gang` | **Thân Bệ Bích Vuông Gang** | Vuông $165 \times 165\text{ mm}$, dày $16\text{ mm}$, bo góc $R15$. Cổ tròn $\varnothing 125\text{ mm}$ cao $60\text{ mm}$, có tai kẹp xẻ rãnh góc $-150^\circ$, vú mỡ tra bi góc $+35^\circ$. | Gang xám đúc FC250 |
| **2** | `2_4_BuLong_M14` | **4 Bu-lông Bắt Mặt Máy** | 4 bộ bu-lông M14 $\times 45\text{ mm}$, kèm long đền phẳng $\varnothing 14\text{ mm}$, tâm 4 lỗ vuông $\pm 65\text{ mm}$ bắt chắc vào mặt máy. | Thép cấp bền 8.8 mạ kẽm |
| **3** | `3_Bac_Dan_UC212` | **Bạc Đạn Đỡ Trục UC212** | Ổ bi lòng cầu tự lựa: Lỗ trong $\varnothing 60\text{ mm}$, đường kính ngoài $\varnothing 110\text{ mm}$, bề rộng $24\text{ mm}$, 8 viên bi cầu thép, 2 phớt cao su chắn bụi kép. | Thép ổ lăn cao cấp GCr15 |
| **4** | `4_Cot_Lap_Phi60` | **Đoạn Cốt Láp Bậc $\varnothing 60$** | Đầu trục $\varnothing 60\text{ mm} \times 110\text{ mm}$, mài bóng cấp chính xác h6, phay rãnh then cavet $18 \times 11\text{ mm}$ dài $50\text{ mm}$ truyền lực puly. | Thép hợp kim C45 tôi cứng |
| **5** | `5_Co_Luc_Giac_Ren` | **Cổ Siết Lục Giác Ren Ngoài** | Lục giác ngoài $S=105\text{ mm}$, ống ren ngoài M100 tịnh tiến tiến/lùi định vị khe hở trống rang. | Thép chế tạo máy C45 |
| **6** | `6_Can_Khoa_Nhanh` | **Cần Gạt Khóa Nhanh** | Tay gạt công thái học dài $65\text{ mm}$ kèm núm tròn $\varnothing 24\text{ mm}$ tại góc $-150^\circ$, siết chặt tai kẹp chống xoay tuột ren. | Thép mạ Chrome & Núm bọc nhựa |
| **7** | `7_Nap_Tron_Va_3_Vit_M4` | **Nắp Tròn Bịt Đầu & 3 Vít M4** | Nắp tròn $\varnothing 86\text{ mm}$ có gờ định tâm, siết bằng 3 vít chìm M4 bố trí đều $120^\circ$, bảo vệ kín khít trục. | Thép dập nguội mạ kẽm |

---

### 15.3. Bố Trí Lắp Ráp Trên 2 Mặt Máy (Tab 1: `1_May_Rang_Cui_Hoan_Chinh`)
* **Cụm Trước ($Y = -518.0\text{ mm}$)**: Bích phẳng áp khít mặt trước của tấm mặt máy trước $18\text{ mm}$, vươn nhô về phía trước (hướng $-Y$), ôm trọn đầu cốt láp trước $\varnothing 60\text{ mm}$.
* **Cụm Sau ($Y = +618.0\text{ mm}$)**: Bích phẳng áp khít mặt sau của tấm mặt máy sau $18\text{ mm}$, vươn nhô về phía sau (hướng $+Y$), ôm trọn đầu cốt láp sau $\varnothing 60\text{ mm}$.
* **Bảng điều khiển GUI tích hợp**:
  * Nút `⚙️ Ẩn/Hiện Bộ Chỉnh Trên Máy`: Bật/tắt nhanh tầm nhìn bộ chỉnh trên cả 2 mặt máy.
  * Nút `🔍 Xuyên Thấu Vỏ Gang (Soi Bi)`: Làm trong suốt thân gang $65\%$ để soi rõ bạc đạn UC212, cốt trục và then cavet đang lắp bên trong.
  * Nút `🔬 Soi Chi Tiết (Tab 3)`: Chuyển thẳng sang Tab 3 để soi kỹ 2 phần.

---

### 15.4. Tổ Chức Tab 3 Riêng Biệt (`3_Bo_Chinh_Goi_Bi_Truc_Phi60`)
* **Phần 1: Tháo Rời 7 Chi Tiết (Exploded View - Bên Trái $X = -280\text{ mm}$)**:
  * Tách rời toàn bộ 7 linh kiện theo trình tự tháo lắp dọc trục $Y$ với khoảng giãn hợp lý:
    * Thân bệ gang đúc $\rightarrow$ 4 Bu-lông M14 $\rightarrow$ Bạc đạn UC212 $\rightarrow$ Cốt láp $\varnothing 60 \rightarrow$ Cổ siết lục giác $S105 \rightarrow$ Cần khóa nhanh $\rightarrow$ Nắp tròn 3 vít M4.
* **Phần 2: Cụm Lắp Ráp Hoàn Chỉnh (Assembled View - Bên Phải $X = +280\text{ mm}$)**:
  * Toàn bộ 7 chi tiết được lắp ăn khớp chính xác $100\%$ theo đúng kích thước hình học và tương tác cơ học thực tế.
* **Hệ thống nút góc nhìn chuyên dụng**:
  * `📐 Phối Cảnh Toàn Bộ`: Quan sát toàn diện cả cụm tháo rời và cụm lắp ráp.
  * `💥 Phần 1: Tháo Rời 7 Chi Tiết`: Tự động zoom đặc tả cụm tháo rời ($X = -280\text{ mm}$).
  * `⭐ Phần 2: Cụm Lắp Ráp Hoàn Chỉnh`: Tự động zoom đặc tả cụm lắp ráp ($X = +280\text{ mm}$).
  * `👁️ Chiếu Đứng (Front)`, `🔝 Chiếu Bằng (Top)`, `👉 Chiếu Cạnh (Right)`.

---

## 16. 4 Cây Láp Giằng Khét Ren 2 Đầu Cố Định 2 Mặt Máy (M16 x 1155mm)
* **Quy cách chế tạo cây láp $\varnothing 16$**:
  * Thân láp tròn đặc $\varnothing 16\text{ mm}$ (Thép hợp kim C45 tôi cải thiện).
  * Chiều dài tổng thể: $L = 1155.0 \pm 0.5\text{ mm}$.
  * Ren ngoài 2 đầu: $M16 \times 2.0-6\text{g}$ (đầu trước dài $30\text{ mm}$, đầu sau dài $60\text{ mm}$).
  * Khoảng cách lọt lòng giữa 2 mặt máy: $1100.0 \pm 0.2\text{ mm}$. Phủ bì 2 mặt máy: $1136.0\text{ mm}$.
* **Vị trí 4 cây láp giằng**:
  * **2 Cây trên**: Tọa độ $(X = \pm 315.0\text{ mm}, Z = +315.0\text{ mm})$, bán kính $R = 445.5\text{ mm}$ (góc $45^\circ$ và $135^\circ$).
  * **2 Cây dưới**: Đưa lên ngay chỗ cuối của đường tròn $R480\text{ mm}$ (góc thắt eo $-40^\circ$), tọa độ $(X = \pm 345.0\text{ mm}, Z = -290.0\text{ mm})$, bán kính $R = 450.7\text{ mm}$.
  * **Khoảng hở an toàn**: Cách vỏ áo trống ($R = 415$) từ $27.7\text{ mm} \rightarrow 30.5\text{ mm}$; cách mép cung tròn mặt máy $R480$ từ $29.3\text{ mm} \rightarrow 34.5\text{ mm}$.
* **Cơ cấu bắt ốc & Mối ghép cải tiến**:
  * **Mặt Máy Trước (18mm)**: Không khoan thủng mặt tiền. Đầu trước cây láp vặn đai ốc M16 áp sát mặt trong ($Y = -500.0\text{ mm}$) và hàn chết chu vi ($a = 3\text{ mm}$) vào mặt máy.
  * **Mặt Máy Sau (18mm)**: Khoan 4 lỗ thông $\varnothing 17.5\text{ mm}$. Cây láp xỏ qua, đệm long đền $\varnothing 32 \times 3\text{ mm}$ và siết cố định bằng 2 con tán kép M16 (Double Jam Nuts) chống rung tự tháo.

---

## 17. Lỗ Vuông Thoát Khói 30x30cm Trên Mặt Máy Sau Phía Trên Bộ Chỉnh
* **Mục đích & Ứng dụng**:
  * Cửa thoát gió nóng, khói và vỏ lụa cà phê trong quá trình rang (Exhaust / Hot Air Outlet), kết nối với ống dẫn gió đi vào Cyclone lắng bụi vỏ lụa và quạt hút ly tâm.
* **Kích thước & Tọa độ hình học**:
  * **Hình dạng**: Lỗ vuông $30\text{ cm} \times 30\text{ cm}$ ($300\text{ mm} \times 300\text{ mm}$).
  * **Vị trí theo trục ngang X**: $X \in [-150.0\text{ mm}, +150.0\text{ mm}]$ (đối xứng qua tâm máy, chiều rộng $W = 300\text{ mm}$).
  * **Vị trí theo trục đứng Z**: $Z \in [+100.0\text{ mm}, +400.0\text{ mm}]$ (chiều cao $H = 300\text{ mm}$).
    * Mép dưới lỗ: $Z = +100.0\text{ mm}$ (nằm ngay phía trên cụm gối bi và bệ chỉnh trục cốt sau).
    * Mép trên lỗ: $Z = +400.0\text{ mm}$ (ngang bằng đúng bán kính ngoài lòng trống rang $R = 400.0\text{ mm}$ để thu trọn luồng khí nóng thoát ra từ các khe hở thông gió đáy sau trống).
  * **Vị trí theo trục dày Y**: Khoét thủng suốt chiều dày $18\text{ mm}$ của tấm Mặt Máy Sau ($Y \in [+600.0, +618.0\text{ mm}]$).
* **Độ hở an toàn & Kết cấu cơ khí**:
  * **Cách đỉnh bệ gối chỉnh**: Mép bệ bích vuông gang $165 \times 165\text{ mm}$ lên tới $Z = +82.5\text{ mm}$. Khoảng cách từ đỉnh bệ gối lên mép dưới lỗ vuông là **$17.5\text{ mm}$** thép tấm 18mm liền khối nguyên vẹn, đảm bảo độ cứng vững tuyệt đối cho 4 bu-lông M14 chân gối.
  * **Cách đỉnh vòm mặt máy**: Đỉnh vòm cong mặt máy sau tại $Z = +480.0\text{ mm}$. Khoảng cách từ mép trên lỗ vuông ($Z = +400.0\text{ mm}$) lên đỉnh vòm là **$80.0\text{ mm}$** ($8\text{ cm}$).
  * **Cách 2 góc vòm ngoài**: 2 góc trên của lỗ vuông $(X = \pm 150\text{ mm}, Z = +400\text{ mm})$ có bán kính $R = \sqrt{150^2 + 400^2} \approx 427.2\text{ mm}$. Khoảng cách tới đường cong mép ngoài mặt máy ($R = 480\text{ mm}$) còn dư an toàn tới **$52.8\text{ mm}$** ($> 5.2\text{ cm}$).
  * **Cách 2 cây láp giằng trên**: Hai cây láp giằng trên ở vị trí $X = \pm 315.0\text{ mm}, Z = +315.0\text{ mm}$. Khoảng cách theo phương ngang từ mép lỗ ($X = \pm 150$) tới tâm cây láp là **$165.0\text{ mm}$** ($16.5\text{ cm}$ mỗi bên), hoàn toàn không cấn vướng bu-lông hay long đền.

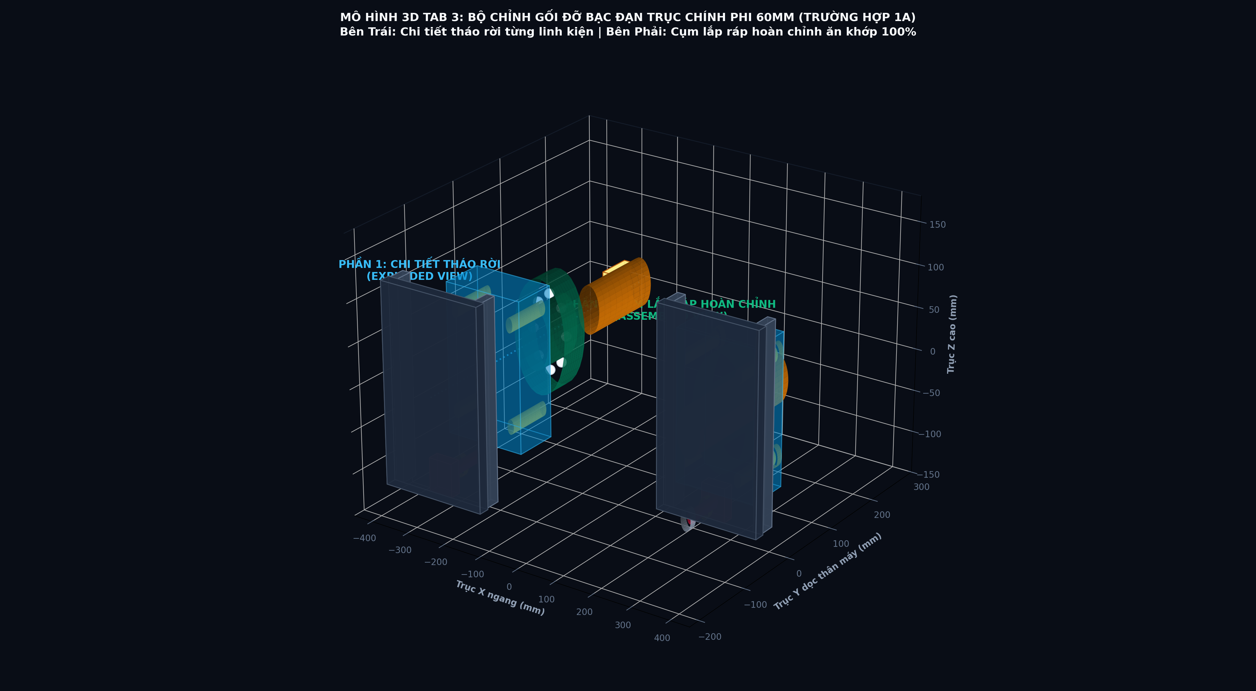
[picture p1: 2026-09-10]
render_3d_bo_chinh_thao_roi_va_lap_rap.png

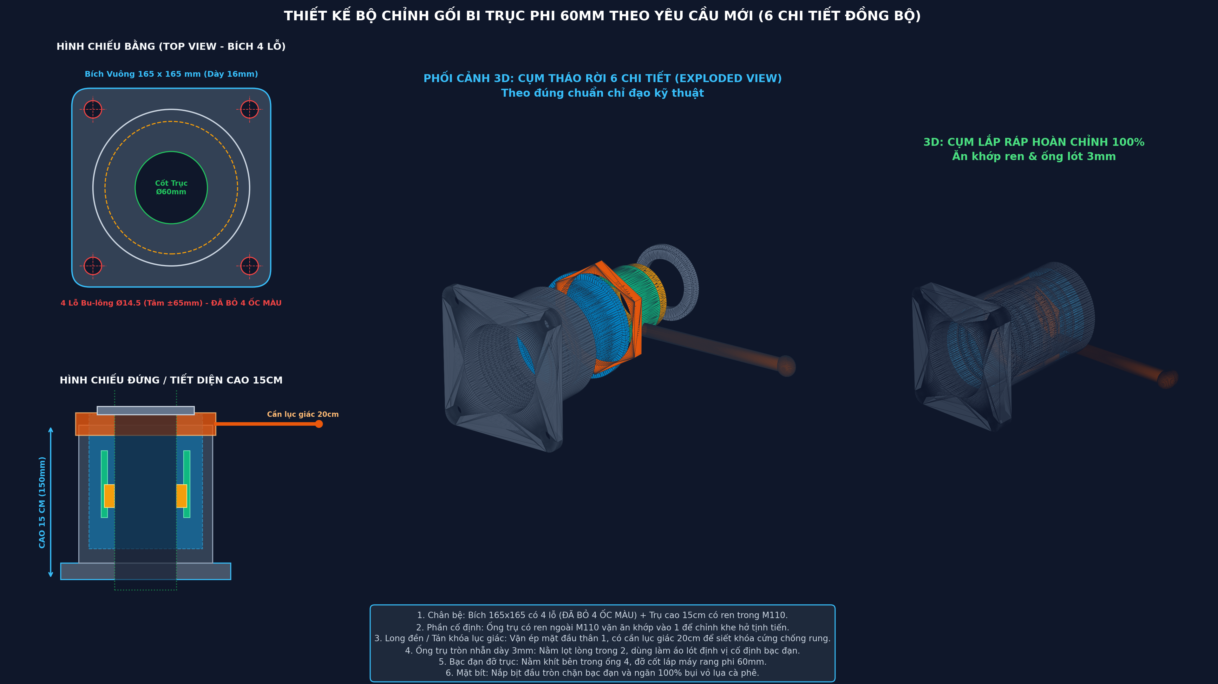
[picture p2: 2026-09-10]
ban_ve_va_render_bo_chinh_6_chi_tiet_moi.png

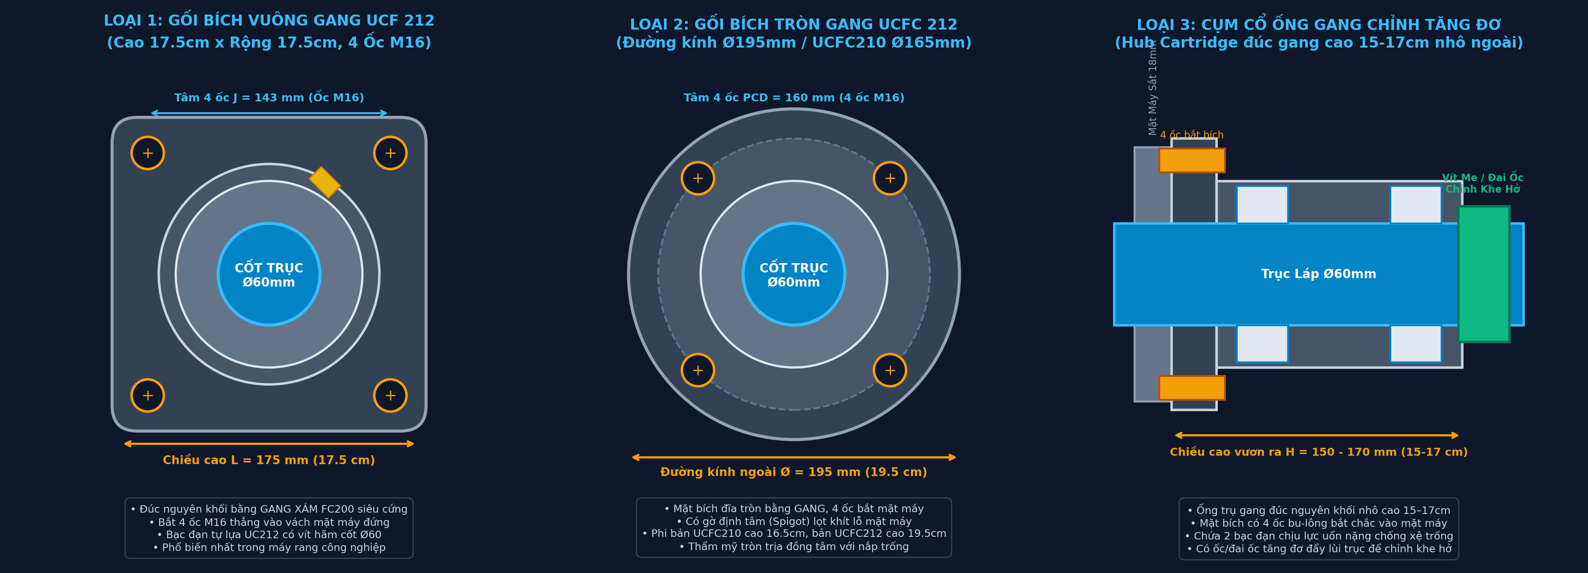
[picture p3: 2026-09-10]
so_sanh_cac_loai_bo_chinh_gang_4_oc.png

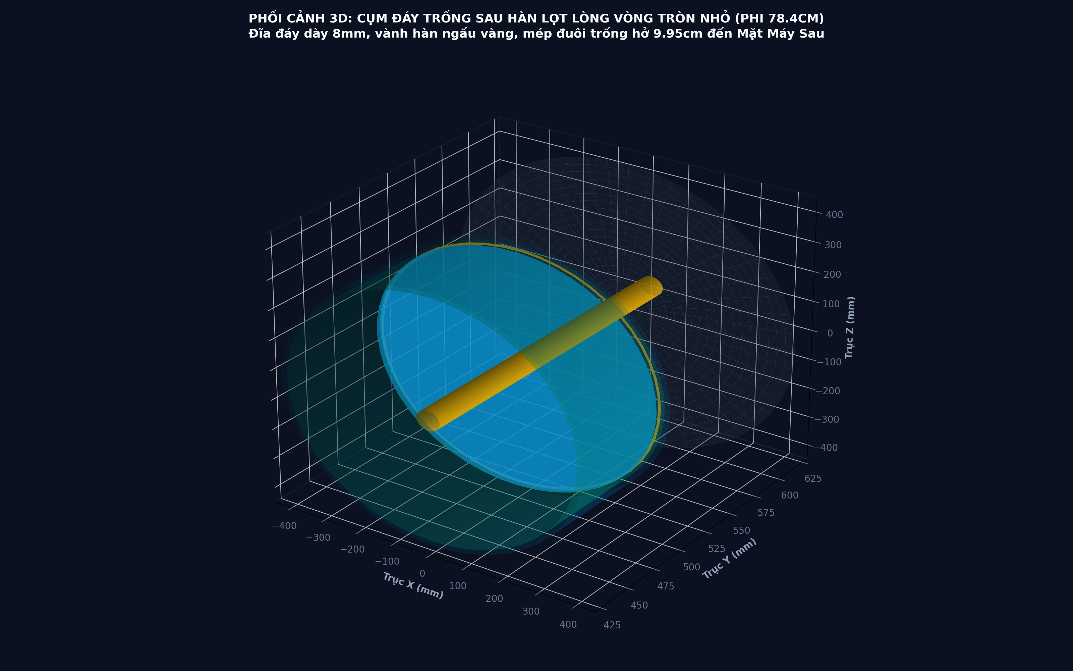
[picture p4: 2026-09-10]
render_3d_tam_sat_tron_day_sau.png

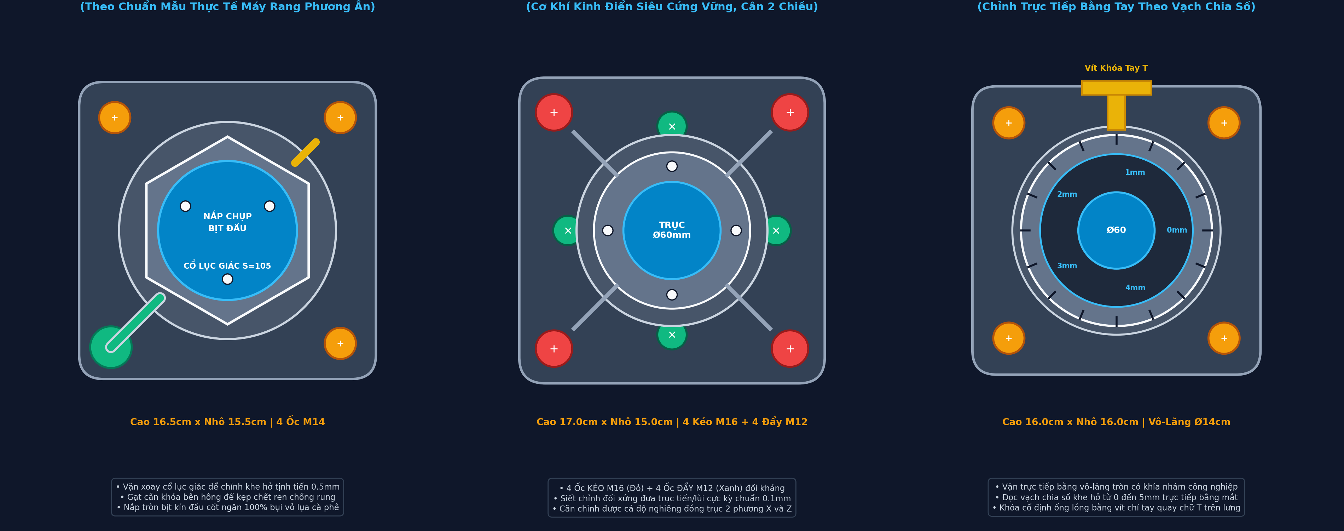
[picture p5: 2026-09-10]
render_3d_3_thiet_ke_bo_chinh_moi.png

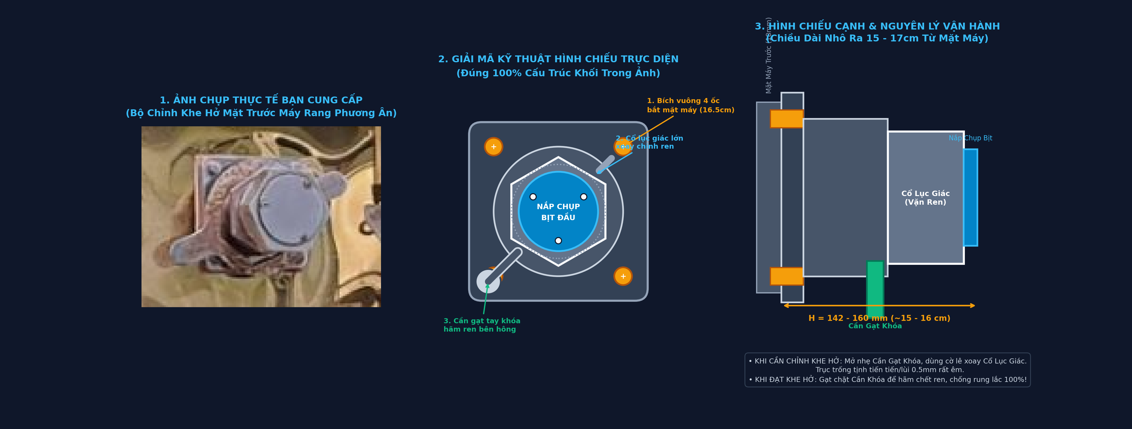
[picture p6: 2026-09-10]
xac_nhan_bo_chinh_phuongan_chuan_100.png

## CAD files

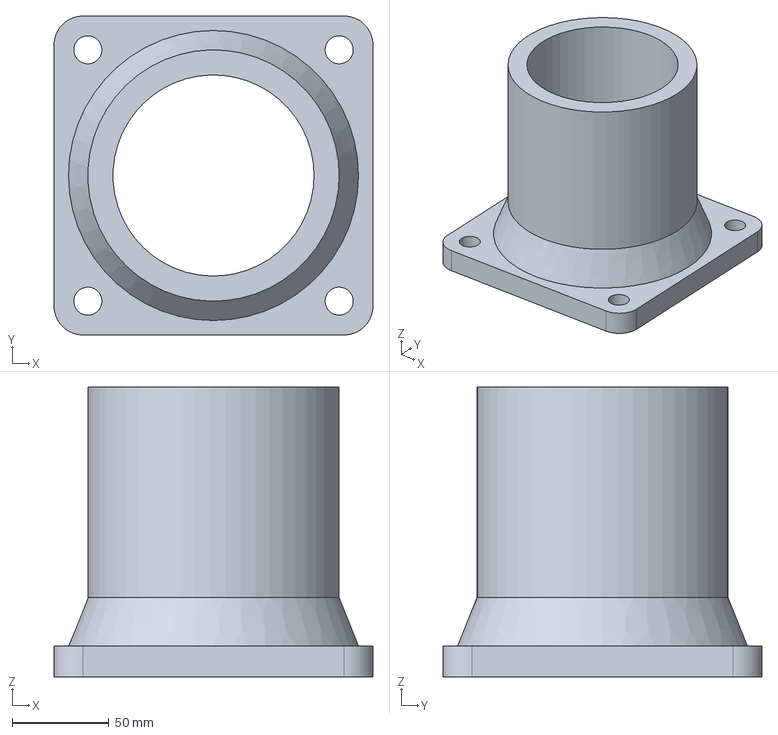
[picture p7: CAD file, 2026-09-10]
step/CT01_Chan_Be_Ren_Trong_M110_H150.step
165.0 x 165.0 x 150.0 mm

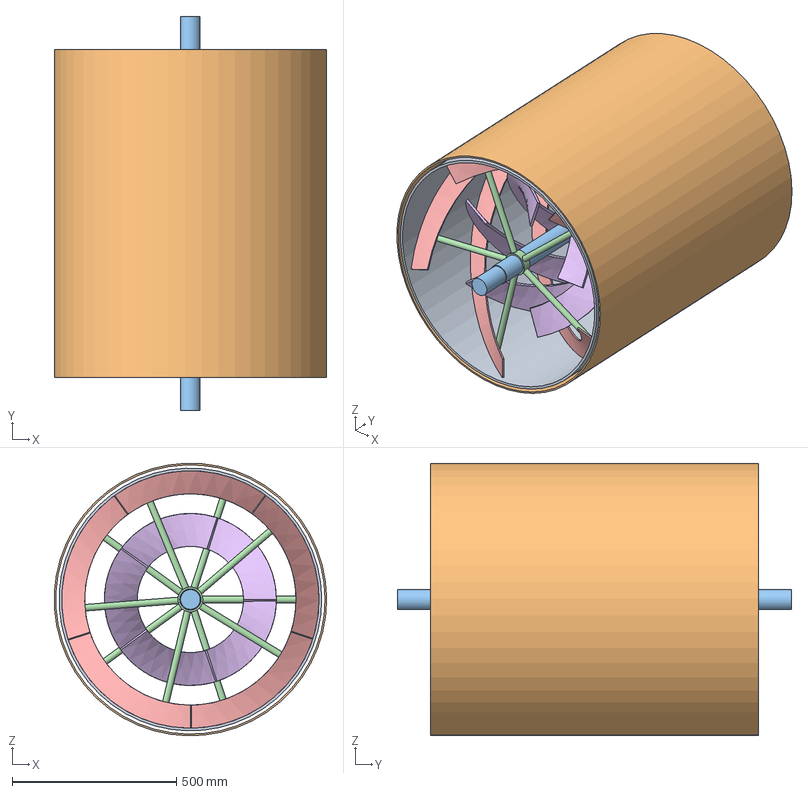
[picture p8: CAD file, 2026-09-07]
Trong_Lap_10Chong_CanhDao_Han_Vao_Cay_Tru.FCStd
829.4 x 1200.0 x 829.6 mm
1. Vỏ Trống Trong (D80cm x L1m x Dày 0.8cm)
1b. Lớp Áo Trống Ngoài (D83cm x Dày 0.5cm, Hở Khí 1cm)
2. Cây Láp Trục Bậc (L1m2, Thân D65mm, 2 Đầu D60mm x 10cm)
3. Hệ Thống 10 Cây Chống Xen Kẽ Nhau 36° (Ống D20mm Dày 2mm)
4. 5 Cánh Đảo Ngoài (La Sắt Bản 7cm, Dày 0.5cm, Xoắn 6/10 Vòng 216°)
5. 5 Cánh Đảo Trong (La Sắt Bản 10cm, Dày 0.8cm, Dài 65cm, Giữa Cây Chống)

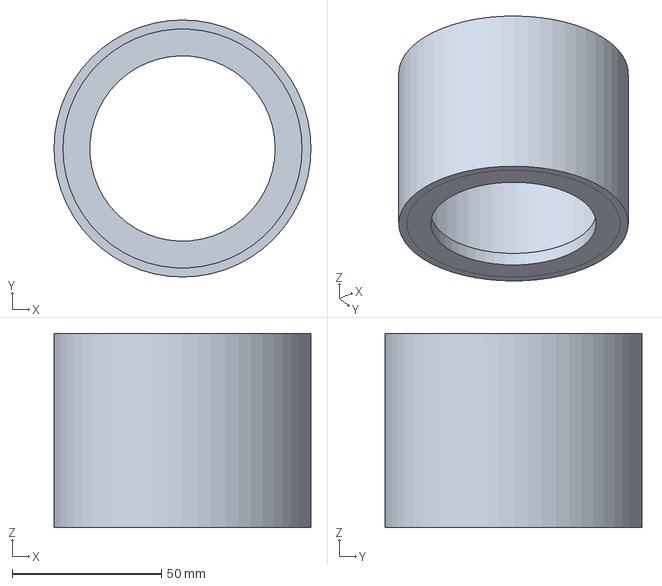
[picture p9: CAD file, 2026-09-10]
step/CT04_Ong_Truot_Tron_Nhan_Day_3mm.step
86.0 x 86.0 x 65.0 mm

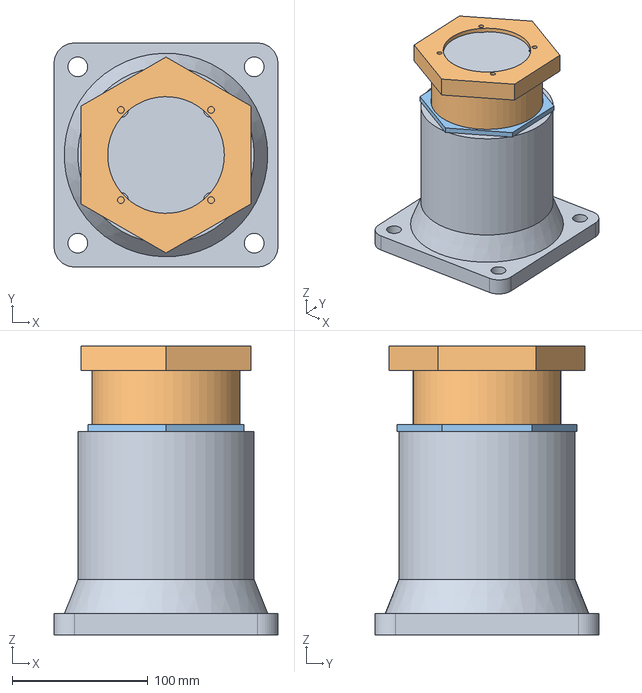
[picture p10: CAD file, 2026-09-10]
step/CUM_BO_CHINH_LAP_RAP_HOAN_CHINH.step
165.0 x 165.0 x 213.0 mm

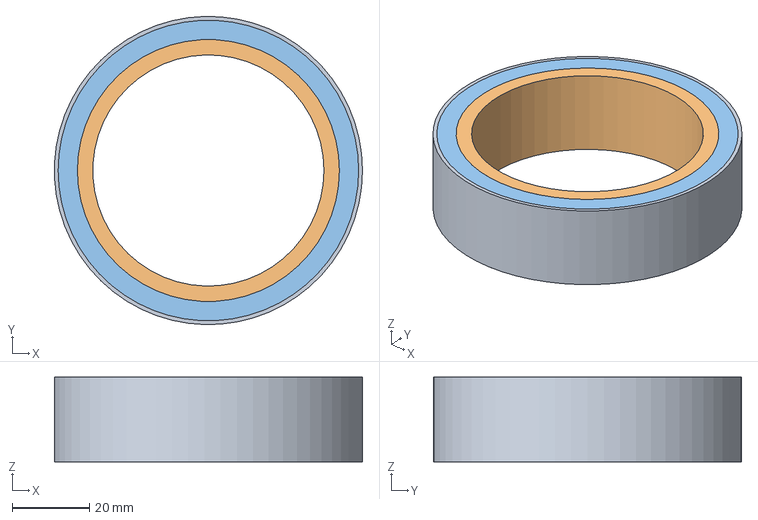
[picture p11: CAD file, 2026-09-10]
step/CT05_Bac_Dan_Do_Truc_Phi60_6012_2RS.step
79.9 x 80.0 x 22.0 mm

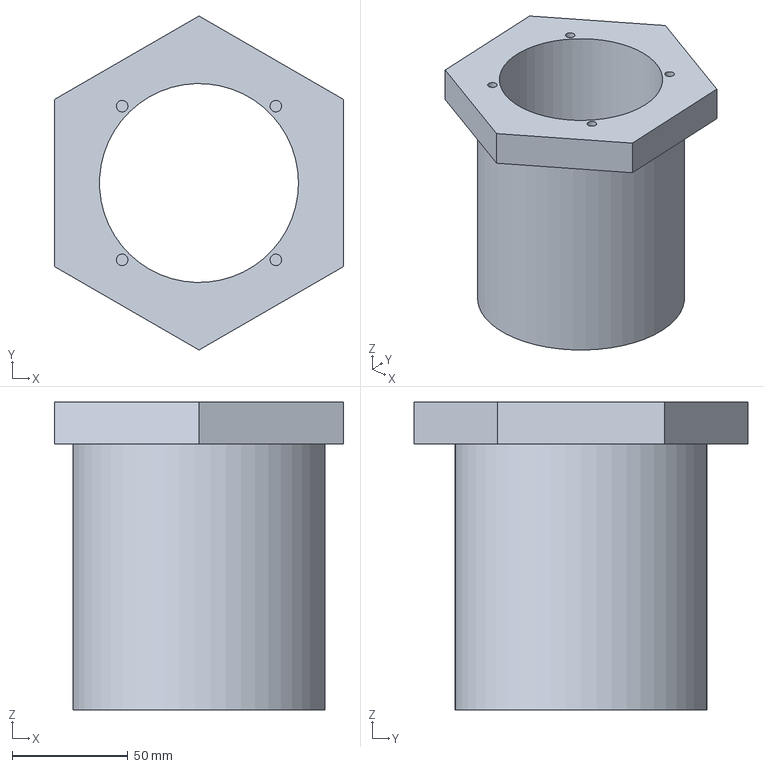
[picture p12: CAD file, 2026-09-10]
step/CT02_Ong_Ren_Ngoai_Luc_Giac_S125.step
125.1 x 144.4 x 133.0 mm

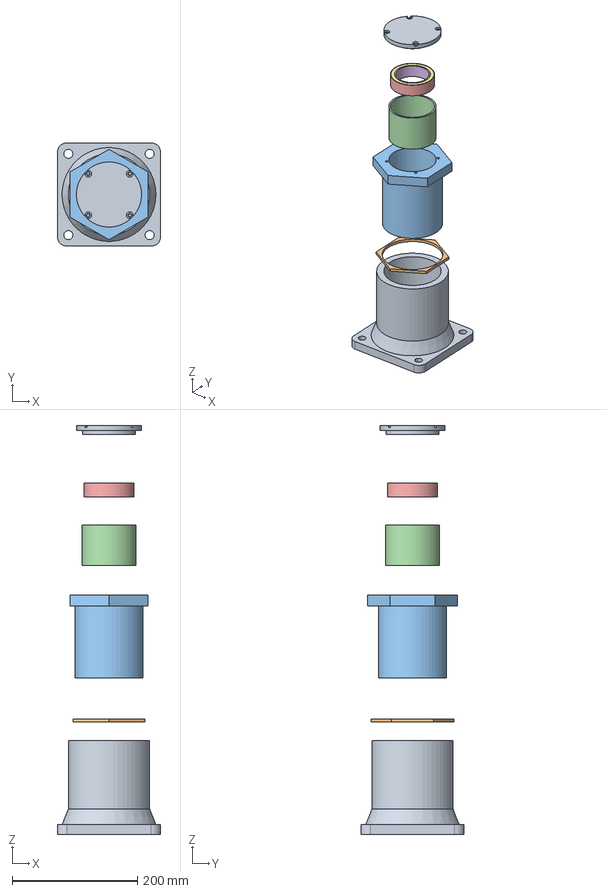
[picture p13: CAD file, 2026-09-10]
step/CUM_BO_CHINH_THAO_ROI_EXPLODED.step
165.0 x 165.0 x 654.0 mm

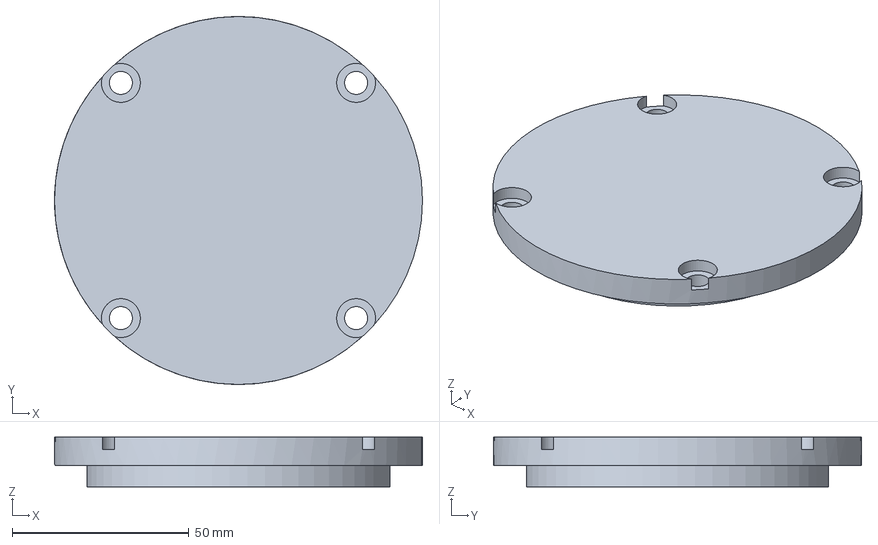
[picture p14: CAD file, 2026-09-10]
step/CT06_Mat_Bit_Nguyen_Khoi_Dac_Kin.step
104.0 x 104.0 x 14.0 mm

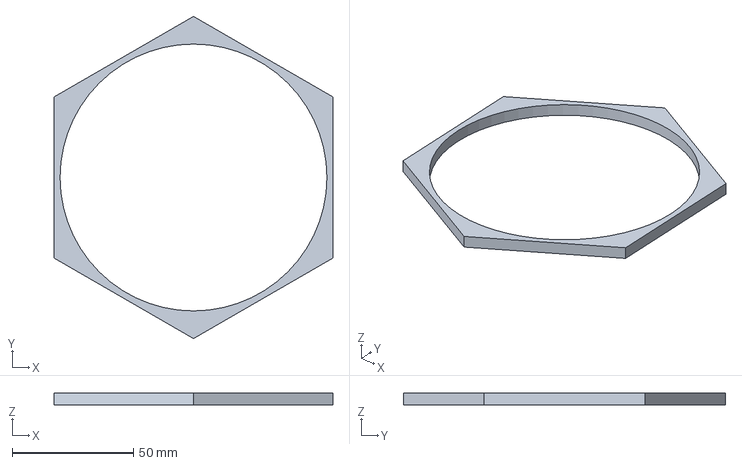
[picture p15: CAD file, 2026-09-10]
step/CT03_Long_Den_Mong_5mm_S115.step
115.0 x 132.8 x 5.00 mm

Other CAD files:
dxf/CT01_Chan_Be_Ren_Trong_M110_H150.dxf
dxf/CT02_Ong_Ren_Ngoai_Luc_Giac_S125.dxf
dxf/CT03_Long_Den_Mong_5mm_S115.dxf
dxf/CT04_Ong_Truot_Tron_Nhan_Day_3mm.dxf
dxf/CT05_Bac_Dan_Do_Truc_Phi60_6012_2RS.dxf
dxf/CT06_Mat_Bit_Nguyen_Khoi_Dac_Kin.dxf

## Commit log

2026-09-10 Thiet ke va lap dat Tam Sat Tron Day Sau Trong Rang lot long Phi 78.4cm day 8mm han ngau
2026-09-10 Hoan tat bo chinh goi bi truc phi 60mm kieu Phuong An chi tiet: xoa bo TK2 va TK3, bo sung 7 linh kien, 2 phan thao roi va lap rap tren Tab 3, lap tren 2 mat may Tab 1
2026-09-10 Cap nhat Tab 3 mo hinh bo chinh 6 chi tiet: Chan be cao 15cm ren trong (bo 4 oc mau), ong ren ngoai, tan khoa luc giac 20cm, ong lot nhan 3mm, bac dan phi 60, mat bit
2026-09-10 Tach xa 6 chi tiet bo chinh 15-17cm doc truc Y tren Tab 3 de nguoi dung de dang quan sat va chi diem sua doi
2026-09-10 Hoan thien tron bo 7 ban ve 2D co khi TCVN, 8 file 3D STEP va 6 file DXF cho bo chinh goi bi phi 60mm
    [CT01_Chan_Be_Ren_Trong_M110_H150.dxf, CT01_Chan_Be_Ren_Trong_M110_H150.step, CT02_Ong_Ren_Ngoai_Luc_Giac_S125.dxf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]
2026-09-10 feat(cad): Hoan tat bo 21 ban ve co khi ky thuat Trong Rang 2 lop theo tieu chuan TCVN/ISO
2026-09-10 feat(cad): Thiet ke 4 Cay Lap Giang khoet ren 2 dau co dinh 2 mat may va xuat 3 ban ve co khi A3 TCVN/ISO
2026-09-10 fix(cad): Cap nhat 2 cay lap giang xuong cuoi duong tron, co cau han oc mat truoc va 2 tan kep mat sau kem 3 ban ve A3 TCVN
2026-09-12 feat(cad): Khoet lo vuong thoat khoi 30x30cm tren mat may sau phia tren bo chinh goi bi
